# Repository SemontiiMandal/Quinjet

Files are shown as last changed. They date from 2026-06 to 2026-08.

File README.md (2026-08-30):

# Quinjet

A custom mini quadcopter and remote controller. Built entirely from scratch, covering the PCB layout, Zephyr firmware, and flight hardware.



## Hardware Design

Both the flight controller and remote controller were designed from scratch in Altium Designer. You can find all design files, including schematics and PCB layouts here, [Altium-Design-Files](https://github.com/SemontiiMandal/Quinjet/tree/main/Altium-Design-Files).

### Four-Layer Flight Controller

The Flight Controller (FC) uses a four-layer stack-up to isolate high-speed digital signals from the power lines driving the motors.

* **Power Delivery:** Features a dedicated boost converter to maintain stable voltage for the nRF52840 and BMI270 under the high current draw of the motors.
* **Battery Monitoring:** The battery voltage is connected to an ADC channel via a voltage divider, allowing the firmware to track real-time power levels.
* **Motor Control:** Uses low-side MOSFET switching with flyback diodes to protect the MCU from motor voltage spikes.

**Layout and 3D View**

<table>
  <tr>
    <td></td>
    <td></td>
    <td></td>
    <td></td>
  </tr>
</table>

**Schematic**



*Download full schematic [here](https://github.com/SemontiiMandal/Quinjet/blob/main/Altium-Design-Files/Mini-Drone/fc_schematic.pdf).*

### Two-Layer Remote Controller

The Remote Controller (RC) is a two-layer board designed for ergonomic input handling.

* **Input Handling:** Interfaces with two dual-axis analog joysticks, sampled directly by the nRF52840’s built-in 12-bit ADC.
* **Interface:** Includes an I2C-based OLED display for real-time telemetry and a PWM-driven haptic motor for tactile alerts.
* **Power Management:** Uses a low-dropout regulator (LDO) to provide clean 3.3V power to the MCU and peripherals, ensuring consistent ADC and sensor readings.
* **Battery Monitoring:** Here too, the battery voltage is connected to an ADC channel via a voltage divider, allowing the firmware to track real-time power levels.

**Layout and 3D View**

<table>
  <tr>
    <td></td>
    <td></td>
  </tr>
  <tr>
    <td></td>
    <td></td>
  </tr>
</table>

**Schematic**



*Download full schematic [here](https://github.com/SemontiiMandal/Quinjet/blob/main/Altium-Design-Files/Mini-Drone-Remote/rc_schematic.pdf).*

---

## System Components and Interconnections

The Quinjet hardware ecosystem consists of two distinct nodes. Each utilizes the nRF52840's peripheral set to handle real-time sensor fusion, radio communication, and motor control.

### Flight Controller (FC) Hardware

* **BMI270 IMU (SPI):** Connects to the nRF52840 via the SPI bus. It uses a dedicated GPIO interrupt pin to wake the flight controller thread exactly when new sensor data is ready, ensuring 1000Hz synchronization.
* **Coreless Motors (Direct-Drive):** Four MOSFETs are driven directly by the nRF52840’s hardware PWM peripherals, operating at 32kHz for silent operation.
* **ESB Radio:** The 2.4GHz radio handles packets asynchronously via the Nordic ESB stack.

### Remote Controller (RC) Hardware

* **Joysticks (SAADC):** Two dual-axis analog joysticks connect to the nRF52840’s SAADC channels, sampled at 100Hz and normalized for transmission.
* **OLED Display (I2C):** Provides the pilot with real-time telemetry and system status.
* **Vibration Motor:** Driven via PWM to provide physical feedback to the pilot.

### Components Summary

| Peripheral | Board | Interface | Purpose |
| --- | --- | --- | --- |
| **BMI270** | FC | SPI | 6-Axis Motion Tracking |
| **Motors (x4)** | FC | PWM | Coreless DC Motor Control |
| **Joysticks** | RC | SAADC | Pilot Input |
| **OLED** | RC | I2C | Telemetry Display |
| **Radio Link** | Both | ESB (2.4GHz) | Low-latency control |

---

## Firmware Architecture

### Flight Controller Board

The Flight Controller (FC) is a high-performance, real-time system engineered to maintain a strict, 1000Hz control loop, ensuring the drone responds to flight dynamics with millisecond precision.

* **Physics-First Timing:** The firmware is driven by a hardware interrupt from the BMI270 IMU. This ensures the flight loop runs at a deterministic 1000Hz, perfectly synchronized to the physical reality of the drone's orientation.
* **Lock-Free Concurrency:** The system uses `k_spinlock` for memory protection, allowing the radio radio to asynchronously dump pilot commands into shared memory without ever blocking the critical PID loop or halting the Zephyr scheduler.
* **Safety & Control:** The system features a custom PID implementation with Anti-Windup logic and a Motor Mixer that acts as a hardware kill-switch, ensuring motors only spin when explicitly armed and commanded.

**For a deep dive into flight dynamics, spinlock logic, and PID tuning, see the [Flight Controller Architecture Documentation](https://github.com/SemontiiMandal/Quinjet/blob/main/firmware/flight_controller/Architecture.md).**

### CMSIS-DSP Library & Filters to Optimize Flight Dynamics

#### Dynamic Notch Filtering & Sliding Window FFT
Motor noise frequencies shift based on throttle. The firmware uses a sliding-window FFT to track this. It maintains an overlapping 64-sample buffer with a hop size of 8. A Hann window is applied, and a fast Fourier transform (`arm_rfft_fast_f32`) executes every 8ms to find the peak noise frequency. A biquad notch filter then removes this frequency before the data reaches the PID controller.

#### Derivative Kick & Anti-Windup
The PID calculates the derivative on the physical measurement instead of the error to prevent derivative kick. It also uses back-calculation anti-windup: if commanded motor output exceeds 100%, the excess power is calculated and drained from the integral term.

#### Dynamic Mixer Scaling & Radio Failsafe
The mixer allows 100% throttle inputs. If a motor exceeds 100% duty cycle, all motors are scaled down equally to preserve differential thrust for stabilization. A radio failsafe checks `k_uptime_get()` and sets PWM to 0 if the RC signal is lost for 500ms.

#### Hardware FPU Optimization
The DSP data path uses 32-bit `float` types exclusively. This ensures sensor fusion and biquad filters execute on the nRF52840's hardware Floating-Point Unit (FPU) instead of using software emulation.

---
### Remote Controller Board

The Quinjet system utilizes a custom, low-latency firmware stack built on **Zephyr RTOS**. The remote controller and flight controller communicate via a proprietary Enhanced ShockBurst (ESB) radio link, sharing a strictly packed data structure for real-time control input.

* **Producer-Consumer Design:** The system uses a lock-free approach where the ADC thread produces joystick state, and the radio thread consumes it via semaphore-driven wakeups.
* **Hardware Safety:** The Remote Controller features a custom state machine that enforces a Zero-Throttle Gate, preventing the drone from arming unless the throttle stick is physically at the zero position.
* **Resource Safety:** Shared memory between threads is protected by mutexes, ensuring thread-safe operations during high-frequency telemetry updates.

**For a deep dive into the firmware design, concurrency models, and interrupt-driven logic, see the [Remote Controller Architecture Documentation](https://github.com/SemontiiMandal/Quinjet/blob/Separate-controller/firmware/remote_controller/Architecture.md).**

---

## Pics of Assembly in progress
WhatsApp Image 2026-06-20 at 6 49 02 PM



## Testing IMU SPI init and value reading (stationary board)


## Testing Remote Controller (RC) Transmission (no RX connected yet)


## Testing Flight Controller


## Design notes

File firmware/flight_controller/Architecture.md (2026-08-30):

# Quinjet Flight Controller Architecture

The Quinjet Flight Controller (FC) runs on an nRF52840 using Zephyr RTOS. The flight control loop executes at 1kHz, driven directly by a hardware interrupt from the BMI270 IMU.

## 1. Core Workflow

The system handles asynchronous radio commands while maintaining a synchronous 1kHz flight loop.

* **IMU Interrupt (1kHz Base):** The BMI270 triggers a hardware interrupt every 1ms when new data is ready. This ISR uses a semaphore (`imu_data_ready_sem`) to wake the flight control thread.
* **Radio Reception:** The ESB radio receives pilot commands asynchronously via the `esb_callback` ISR.
* **Spinlock Protection:** Radio data is protected using `k_spinlock`. This briefly disables local CPU interrupts to safely copy data into shared memory without halting the Zephyr scheduler or delaying the 1kHz loop.
* **Radio Failsafe:** The thread checks Zephyr's `k_uptime_get()`. If no valid radio packet is received for 500ms, the system triggers a hardware failsafe, dropping motor duty cycles to 0.
* **Flight Control Thread:** Statically allocated (`K_THREAD_DEFINE`) as a cooperative thread (Priority -1). It wakes, executes DSP and PID calculations uninterrupted, and immediately yields back to the scheduler.

## 2. Flight Dynamics

* **Back-Calculation Anti-Windup:** The PID loops track hardware saturation. If outputs demand more than 100% motor power, the system calculates the excess "phantom power" and subtracts it from the integral memory to prevent overshoot.
* **Measurement Derivative:** The D-term is calculated on the rate of change of the physical measurement rather than the error, preventing derivative kick during rapid joystick movements.
* **Dynamic Mixer Scaling & AirMode:** The motor mixer evaluates all four commanded outputs. If a motor exceeds 100% duty cycle, the mixer mathematically scales all four motors down equally to preserve differential thrust without an artificial throttle cap. It also scales motors up (AirMode) if they drop below minimum idle speed to maintain stabilization during free-fall.

## 3. Digital Signal Processing (DSP) Pipeline

The DSP pipeline cleans the raw sensor data before feeding it to the PID controller.

* **Data Ingestion (1kHz):** Driven by the 1ms IMU interrupt, raw accelerometer and gyroscope data is read and cast directly to 32-bit `float` variables. This locks the pipeline inside the nRF52840's hardware Floating-Point Unit (FPU), bypassing software math emulation.
* **Sliding Window FFT:** The system uses `memmove` to shift an overlapping 64-sample buffer every 1ms. Every 8ms (an 8-sample hop size), a pre-calculated Hann window is applied, and a CMSIS-DSP fast Fourier transform (`arm_rfft_fast_f32`) executes to identify the dominant motor resonance in the 100Hz–400Hz band.
* **Dynamic Notch Filter:** A biquad notch filter updates its center frequency based on the FFT output to mathematically remove the specific motor vibration peak from the gyroscope data.
* **Sensor Fusion:** A complementary filter (`Angle = 0.98 * (Angle + Gyro * dt) + 0.02 * Accel_Angle`) calculates orientation. It uses the gyroscope for short-term tracking and the accelerometer as a long-term reference to correct drift.
* **D-Term Smoothing:** The D-term passes through an independent 30Hz CMSIS biquad low-pass filter to prevent high-frequency noise from reaching the motors.

## 4. Architectural Design Concepts

| Concept | Implementation Strategy |
| --- | --- |
| **Interrupt-Safe Memory** | Using `k_spinlock` instead of mutexes ensures the radio can dump data into shared memory without halting the Zephyr scheduler or delaying the 1000Hz flight loop. |
| **No Stale Data** | We do not queue or buffer incoming radio packets. The PID loop only reads the single newest command. Queuing would force the drone to execute outdated maneuvers. |
| **High-Frequency PWM** | The DeviceTree overrides standard PWM defaults to drive the coreless motors at **32 kHz**. This is above human hearing and prevents electrical switching noise from interfering with the IMU. |

## 5. Logical Flow Summary

The system runs a continuous, low-latency loop, triggered by the IMU data-ready interrupts:

1. **Input:** The Radio ISR updates the shared memory buffer with pilot commands in the background.
2. **Trigger:** The BMI270 finishes a reading and fires an interrupt, waking the main thread.
3. **Failsafe Check:** The thread verifies the radio connection timestamp via OS uptime.
4. **Processing:** The thread fetches the IMU data, runs the DSP pipeline, executes Sensor Fusion, and calculates Pitch, Roll, and Yaw PID corrections.
5. **Mixing:** The PID outputs are mapped to the physical Quad-X motor layout using dynamic overflow scaling.
6. **Output:** The final duty cycles (0–10000) are sent to the hardware PWM registers to update the motor speeds.

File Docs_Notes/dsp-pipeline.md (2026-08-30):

# Quinjet Digital Signal Processing (DSP) Pipeline

## 1. Data Ingestion & Formatting

The BMI270 IMU triggers a hardware interrupt every 1 millisecond. Raw 16-bit integer readings are fetched via SPI and immediately converted into standard floating-point metrics (m/s² for acceleration, rad/s for angular velocity). This strictly enforces FPU hardware execution for all subsequent stages.

## 2. Resonance Detection (Sliding Window FFT)

Motors and propellers generate high-frequency vibrations that travel through the frame into the gyroscope. To find this noise peak without delaying the flight loop, we use an overlapping sliding window FFT.

* **The Buffer Shift:** Every 1ms, a 64-sample buffer shifts left by one, dropping the oldest reading and appending the newest.
* **The Hop Size:** Every 8 milliseconds, the FFT executes on the 64-sample snapshot.
* **The Hann Window:** Before the FFT runs, the raw data is multiplied by a Hann window to taper the edges to zero. This prevents the FFT from seeing the chunk's boundaries as sudden, high-frequency "cliffs" (spectral leakage). The window is pre-calculated on boot:

$$w[n] = 0.5 \left( 1 - \cos\left(\frac{2\pi n}{N-1}\right) \right)$$

* **Magnitude Calculation:** The CMSIS-DSP `arm_rfft_fast_f32` function returns interleaved real and imaginary numbers. The true amplitude of each frequency bin $k$ is calculated as:

$$M[k] = \sqrt{\text{Re}(X[k])^2 + \text{Im}(X[k])^2}$$

The algorithm scans the 100Hz–400Hz range to pinpoint the exact frequency $f_c$ with the highest magnitude.

## 3. Dynamic Notch Filtering

Once the FFT identifies the peak motor resonance, passing it through a Biquad Notch Filter eliminates specific frequency from the gyroscope data.

As the pilot adjusts the throttle and the motor RPM shifts, the FFT detects the new vibration frequency and dynamically recalculates the biquad filter coefficients ($a_n$, $b_n$). The filter operates using the standard discrete-time transfer function:

$$H(z) = \frac{b_0 + b_1 z^{-1} + b_2 z^{-2}}{a_0 + a_1 z^{-1} + a_2 z^{-2}}$$

This basically neutralizes motor noise while passing the lower-frequency physical drone rotations through.

## 4. Sensor Fusion (Complementary Filter)

Now the system determines the drone's true orientation by fusing the gyroscope and accelerometer.

* **Accelerometer (Absolute but Noisy):** Trigonometry determines the angle relative to gravity.

$$\phi_{acc} = \arctan\left(\frac{a_y}{\sqrt{a_x^2 + a_z^2}}\right)$$

* **Gyroscope (Fast but Drifts):** The angular velocity is multiplied by the loop time ($dt = 0.001$) to find the rotation amount.
* **The Fusion:** A complementary filter merges them. It trusts the gyroscope for 98% of the split-second maneuver and mixes in 2% of the accelerometer to permanently anchor the horizon and prevent gyro drift:

$$\theta = \alpha (\theta + \omega dt) + (1 - \alpha) \theta_{acc}$$

*(where $\alpha = 0.98$)*

## 5. PID Control & D-Term Smoothing

Next, the PID controller calculates the motor adjustments needed to match the pilot's requested angle.

* **Measurement Derivative:** Derivative kick is a sudden, massive spike in the control output of a PID controller caused by an abrupt change in the setpoint. To prevent derivative kick if the pilot rapidly changes the joystick to a new setpoint, the derivative (braking) force is calculated purely on the rate of change of the drone's physical movement, ignoring the mathematical error:

$$D_{raw} = -\left(\frac{\text{Measured}_t - \text{Measured}_{t-1}}{dt}\right)$$

* **D-Term Low-Pass Filter:** Because taking a derivative mathematically amplifies any microscopic jitter left over from the notch filter, the raw D-term is passed through a dedicated 30Hz Biquad Low-Pass filter before it can multiply with the $K_d$ gain.
* **Back-Calculation Anti-Windup:** If the final PID output demands a duty cycle greater than 100%, the difference ($E_{excess}$) is instantly subtracted from the integral sum ($I_{sum}$) scaled by a back-tracking gain ($K_b$). This ensures the integral memory never winds up beyond the physical limits of the motors:

$$I_{sum} = I_{sum} - (E_{excess} \cdot K_b \cdot dt)$$

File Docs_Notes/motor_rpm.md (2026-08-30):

# 8520 Coreless Motor PWM Control Profile

This document details the relationship between the applied **32 kHz PWM signal** and the resulting **RPM** for the Powerday 8520 coreless brushed motor powered by a **4.2V lipo battery source**.

---

## 1. Motor & Signal Parameters

### Baseline Specifications
* **Max Speed (No-Load):** 53,000 RPM @ 5.0V
* **Target Source Voltage ($V_{\text{source}}$):** 4.2V (1S LiPo max)
* **PWM Carrier Frequency ($f$):** 32,000 Hz (32 kHz)

### Derived Constants
* **Motor Velocity Constant ($K_v$):**
  $$K_v = \frac{53,000 \text{ RPM}}{5.0\text{V}} = 10,600 \text{ RPM/V}$$
* **PWM Period ($T$):** The exact timeframe for one complete ON/OFF cycle.
  $$T = \frac{1}{f} = \frac{1}{32,000 \text{ Hz}} = 31.25\ \mu\text{s}$$

---

## 2. Core Mathematical Formulas

The system relies on three interconnected equations to translate software values to mechanical motion:

1. **Pulse ON Time ($T_{\text{on}}$):**
   $$T_{\text{on}} = T \times \text{Duty Cycle } (D)$$
2. **Average Output Voltage ($V_{\text{avg}}$):**
   $$V_{\text{avg}} = V_{\text{source}} \times \text{Duty Cycle } (D)$$
3. **Theoretical Motor Speed ($\text{RPM}_{\text{ideal}}$):**
   $$\text{RPM}_{\text{ideal}} = V_{\text{avg}} \times K_v$$

---

## 3. Detailed Duty Cycle Calculations (4.2V Source)

Below are three operational reference scenarios calculated across the voltage profile.

### Scenario A: 100% Duty Cycle (Full Throttle)
* **Duty Cycle ($D$):** $1.0$
* **ON Time ($T_{\text{on}}$):** $31.25\ \mu\text{s} \times 1.0 = 31.25\ \mu\text{s}$ (Continuous high state)
* **Average Voltage ($V_{\text{avg}}$):** $4.2\text{V} \times 1.0 = 4.2\text{V}$
* **Calculation:**
  $$\text{RPM} = 4.2\text{V} \times 10,600 \text{ RPM/V} = \mathbf{44,520 \text{ RPM}}$$

### Scenario B: 75% Duty Cycle (Cruising Speed)
* **Duty Cycle ($D$):** $0.75$
* **ON Time ($T_{\text{on}}$):** $31.25\ \mu\text{s} \times 0.75 = 23.4375\ \mu\text{s}$
* **Average Voltage ($V_{\text{avg}}$):** $4.2\text{V} \times 0.75 = 3.15\text{V}$
* **Calculation:**
  $$\text{RPM} = 3.15\text{V} \times 10,600 \text{ RPM/V} = \mathbf{33,390 \text{ RPM}}$$

### Scenario C: 25% Duty Cycle (Low Speed/Idle)
* **Duty Cycle ($D$):** $0.25$
* **ON Time ($T_{\text{on}}$):** $31.25\ \mu\text{s} \times 0.25 = 7.8125\ \mu\text{s}$
* **Average Voltage ($V_{\text{avg}}$):** $4.2\text{V} \times 0.25 = 1.05\text{V}$
* **Calculation:**
  $$\text{RPM} = 1.05\text{V} \times 10,600 \text{ RPM/V} = \mathbf{11,130 \text{ RPM}}$$

---

## 4. Summary Duty Cycle to RPM Lookup Table

The following theoretical lookup table assumes an 8-bit resolution microcontroller layout (0 - 255 steps) mapping to the 4.2V ceiling.

| 8-Bit Step | Duty Cycle (%) | Average Voltage ($V_{\text{avg}}$) | Theoretical No-Load RPM |
| :--- | :--- | :--- | :--- |
| **255** | 100% | 4.20V | 44,520 RPM |
| **204** | 80% | 3.36V | 35,616 RPM |
| **153** | 60% | 2.52V | 26,712 RPM |
| **102** | 40% | 1.68V | 17,808 RPM |
| **51** | 20% | 0.84V | 8,904 RPM |
| **25** | ~10% | 0.42V | *Friction Threshold Boundary* |

---

## 5. Physical Implementation Constraints

1. **Aerodynamic Loading (75mm Propeller):** 
   The calculation yields *no-load* RPM metrics. Attaching the 75mm propeller introduces aerodynamic drag torque. Because propeller power demands scale cubically with velocity ($P \propto \text{RPM}^3$), the linear voltage-to-RPM relationship will **flatten out aggressively at high duty cycles**. Actual operational RPM will sit lower than theoretical models.
2. **High Carrier Frequency Advantage:** 
   Utilizing a **32 kHz** carrier provides an ultrashort period ($31.25\ \mu\text{s}$). Coreless motors have ultra low core inductance, so standard low-frequency PWM signals cause current ripples, causing heating up and motor ripple. A 32 kHz frequency not only ensures clean and steady DC equivalence, but also dampens audible switching out of human hearing range!

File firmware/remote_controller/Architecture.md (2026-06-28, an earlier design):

# Quinjet RC Controller Architecture

The Quinjet Remote Controller firmware is a real-time system built on the **nRF52840** and **Zephyr RTOS**. It is engineered to maintain a strict, low-latency hot path from the user’s fingertips to the radio transmitter, ensuring the drone responds instantly to pilot commands.

## 1. Core Workflow

The system operates as a producer-consumer engine where data flows from hardware sensors to the radio link through protected memory.

* **Joystick Sampling (Producer):** The `adc_thread` runs a deterministic 100Hz loop (every 10ms). It queries four ADC channels, converts the raw 12-bit hardware values into normalized floating-point coordinates (`-1.0` to `1.0`), and applies dead-zone and jitter compensation logic.
* **Resource Protection:** To prevent "data tearing" (where the radio sends a partially updated packet), the system **protects shared resources with a mutex** (`joystick_data`). The ADC thread locks this mutex before updating the shared `data_packet`, and the radio thread locks it before reading the payload.
* **Thread Synchronization:** Efficiency is achieved by letting the radio thread sleep when no new data is present. The ADC thread **wakes the radio thread by giving a semaphore** (`wake_esb`) immediately after it has finished refreshing the shared memory, effectively triggering the transmission only when absolutely necessary.
* **Air Link (Consumer):** The `esb_tx_thread` remains blocked, consuming zero CPU cycles until the semaphore wakes it. Once active, it creates a local snapshot of the control state, releases the mutex, and blasts the packet over the 2.4GHz Enhanced ShockBurst (ESB) link.

## 2. Safety and State Management

Flying hardware requires strict safety gates. We move away from polling in favor of hardware-level event handling.

* **Interrupt-Driven Logic:** The `rc_state_machine` uses physical GPIO interrupts on the joystick buttons. When a button is pressed, the ISR fires instantly to flip a `volatile bool` flag. This avoids the latency and CPU waste of checking pin states in a loop.
* **The Zero-Throttle Gate:** We implement a software-defined safety gate. The transition from `IDLE` to `ARMED` is only permitted if the `throttle` coordinate is below `0.05f` (near zero). This prevents the drone from jumping into the air if the stick is accidentally left pushed forward during the arming sequence.

## 3. Architectural Design Concepts

| Concept | Implementation Strategy |
| --- | --- |
| **Data Packing** | We use `__attribute__((packed))` on the shared `data_packet` struct. This forces the compiler to ignore padding bytes, ensuring the RC transmitter and FC receiver interpret the memory layout identically over the air. |
| **Modularity** | The system is split into `rc/`, `fc/`, and `shared/` directories. Common structs (like the 20-byte `data_packet`) reside in `shared/`, ensuring that if you update your packet format, both boards stay in sync. |
| **Jitter Mitigation** | The `decode_joystick` module performs software-based noise filtering on ADC samples. By mapping raw values to a consistent coordinate space, the flight controller remains agnostic to the specific potentiometer hardware used. |
| **Deterministic Timing** | By using `k_msleep(10)` for our control loop, we provide the Flight Controller with a perfectly steady stream of data, which is essential for stable PID loop performance. |

## 4. Logical Flow Summary

The system behaves as a synchronous link between the pilot and the flight hardware:

1. **Input:** Pilot moves the joysticks or toggles the arm button.
2. **Processing:** The ADC thread performs normalization and enforces the "Zero-Throttle" safety gate.
3. **Synchronization:** The shared memory is updated, and the radio thread is woken via semaphore.
4. **Transmission:** The radio thread copies the struct, handles ESB auto-ACKs, and pushes the data to the air interface.

This architecture ensures that the hot path is never blocked by slow radio hardware or erratic button presses, providing the literal locked-in feel required for reliable flight control!

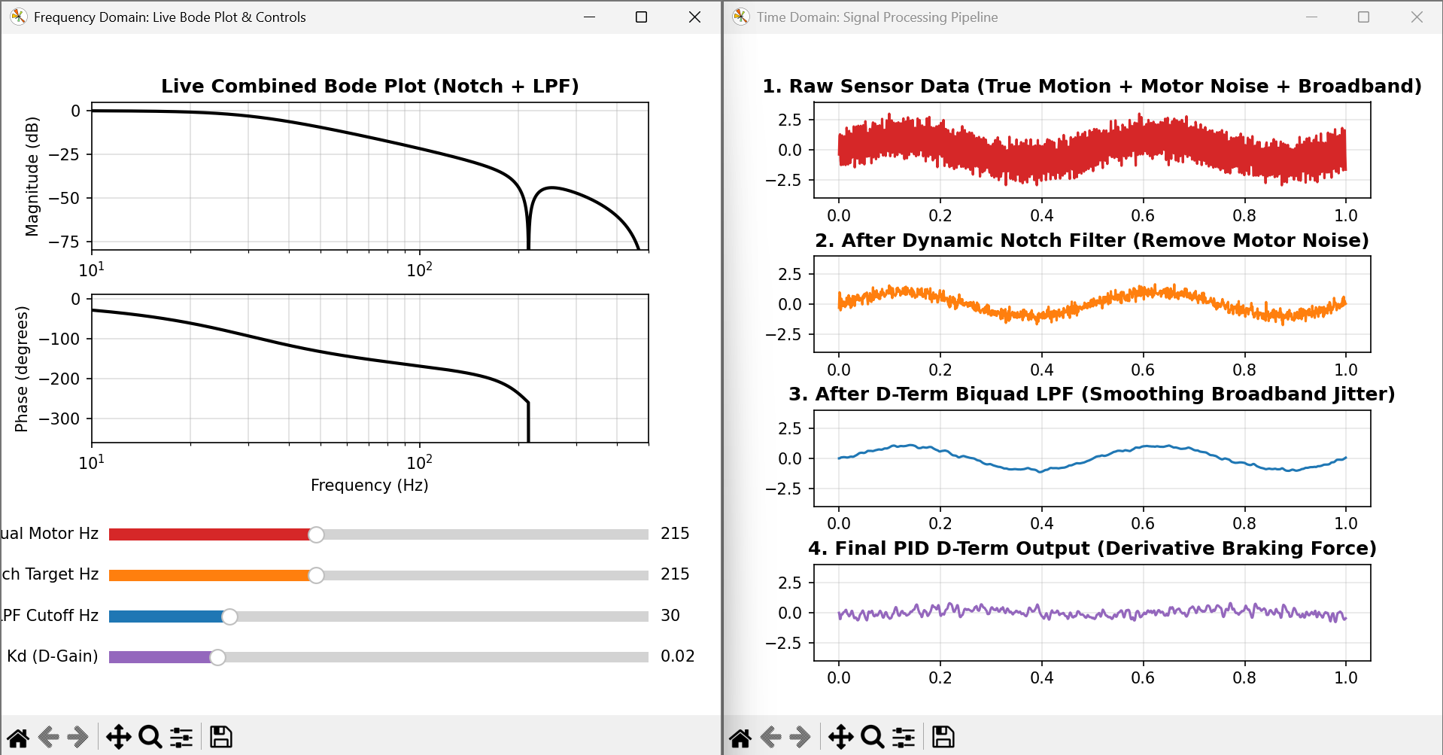
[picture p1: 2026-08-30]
software/simulations_dsp.png

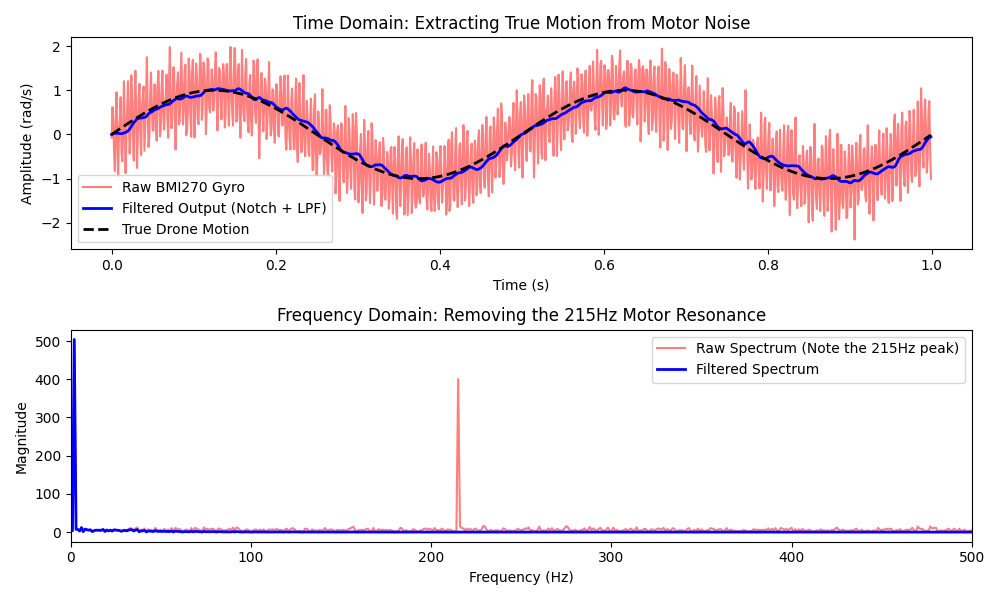
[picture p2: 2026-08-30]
software/dsp_pipeline_stage.png

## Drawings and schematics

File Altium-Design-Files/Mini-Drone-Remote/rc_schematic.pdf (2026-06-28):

REVISION | DESCRIPTION | DATE | APPROVED | REV. SHT. <SCH DWG NO> 1 DWG. NO.

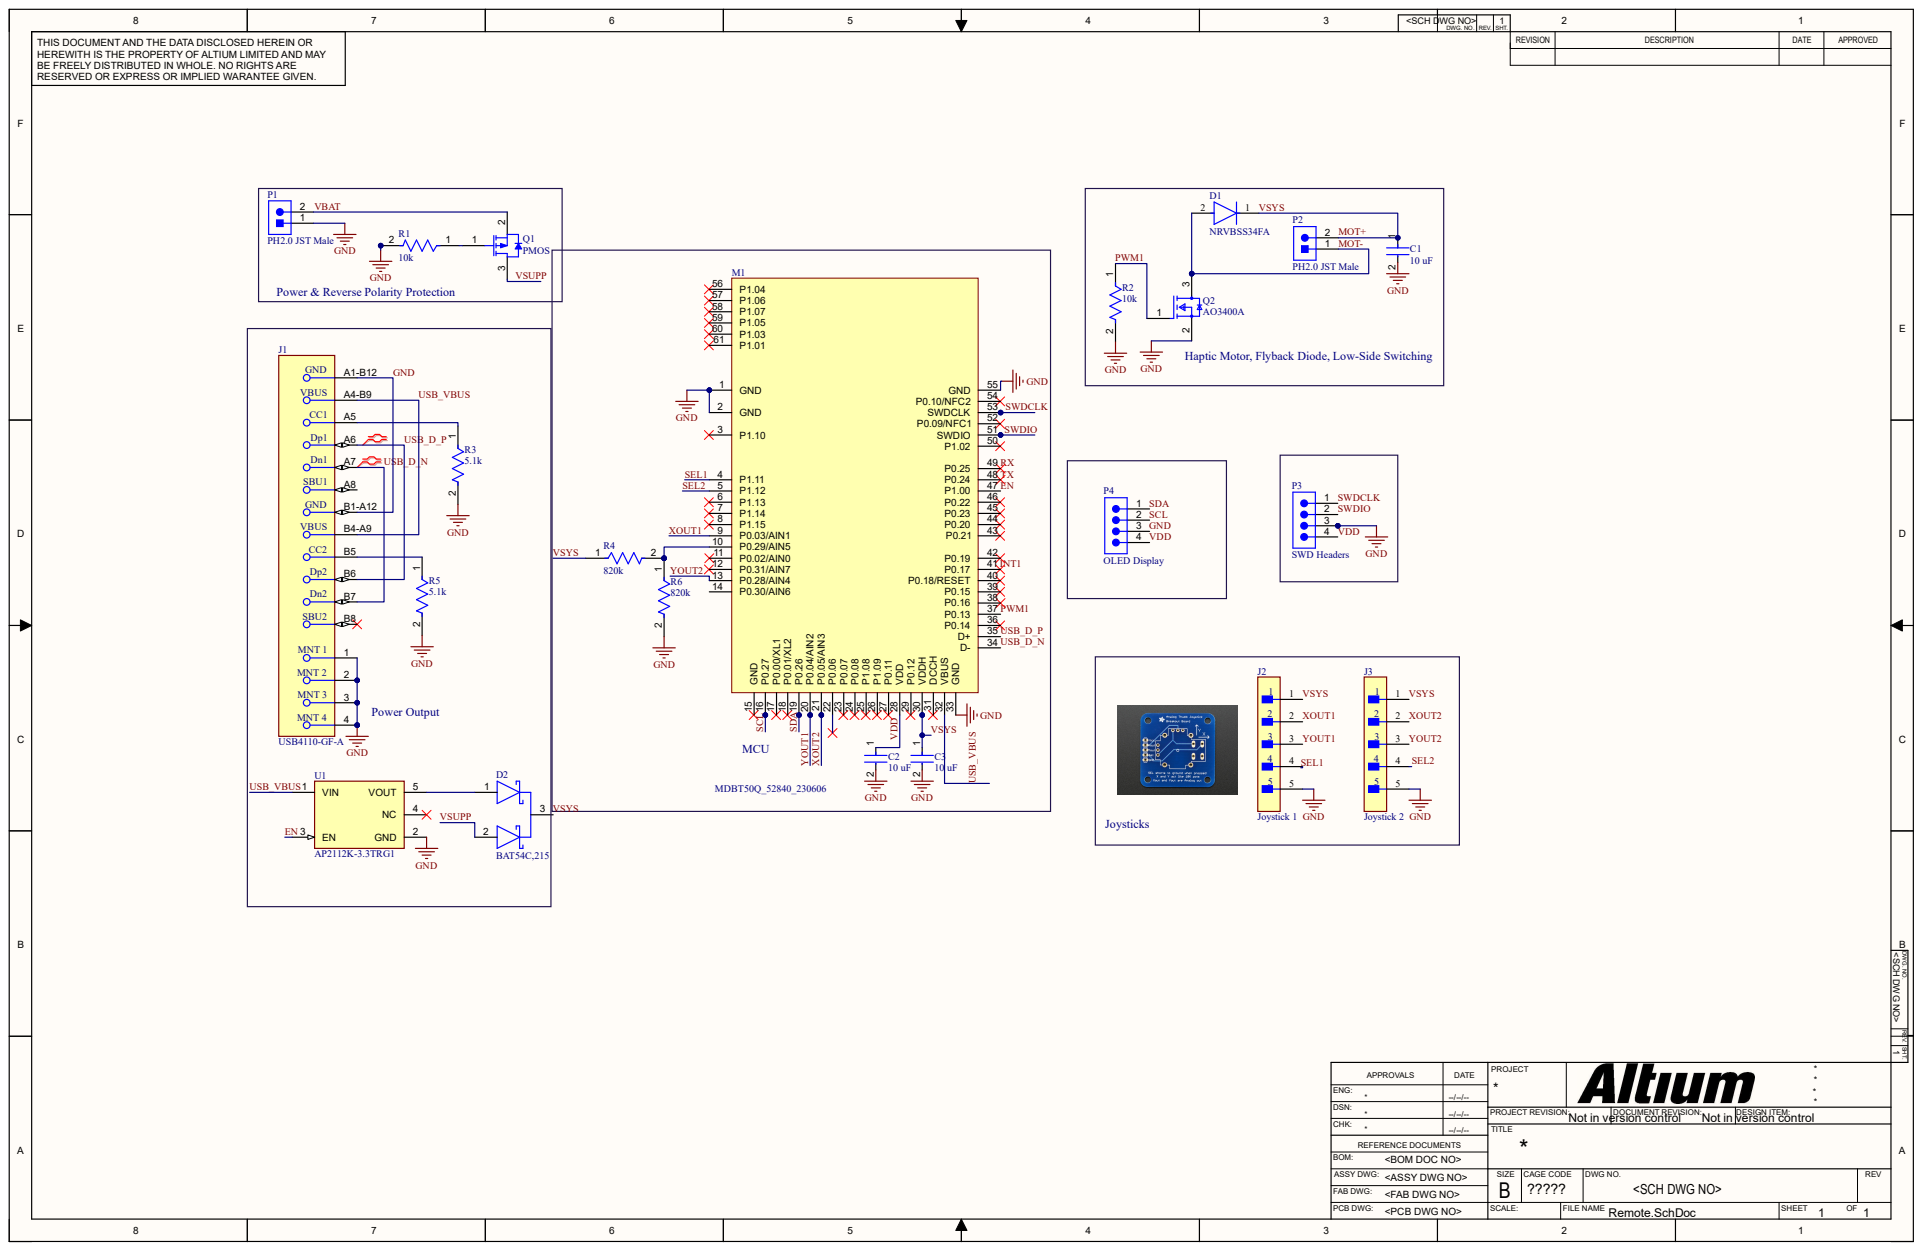
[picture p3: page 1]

8 | 7 | 6 | 5 | 4 | 3 | <SCH DWG NO> | DWG. NO. | REV. | 1 SHT. | 2 | 1

THIS DOCUMENT AND THE DATA DISCLOSED HEREIN OR HEREWITH IS THE PROPERTY OF ALTIUM LIMITED AND MAY BE FREELY DISTRIBUTED IN WHOLE. NO RIGHTS ARE RESERVED OR EXPRESS OR IMPLIED WARANTEE GIVEN. | D1

Power & Reverse Polarity Protection

Haptic Motor, Flyback Diode, Low-Side Switching

APPROVALS | DATE | PROJECT * | * *

ENG: * | --/--/--
CHK: * | --/--/-- | TITLE *

DSN: * | --/--/-- | PROJECT REVISION: | DOCUMENT REVISION: Not in version control | DESIGN ITEM: Not in version control

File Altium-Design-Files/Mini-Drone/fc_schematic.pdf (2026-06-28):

REVISION | DESCRIPTION | DATE | APPROVED | REV. SHT. <SCH DWG NO> 1 DWG. NO.

10k 1 2

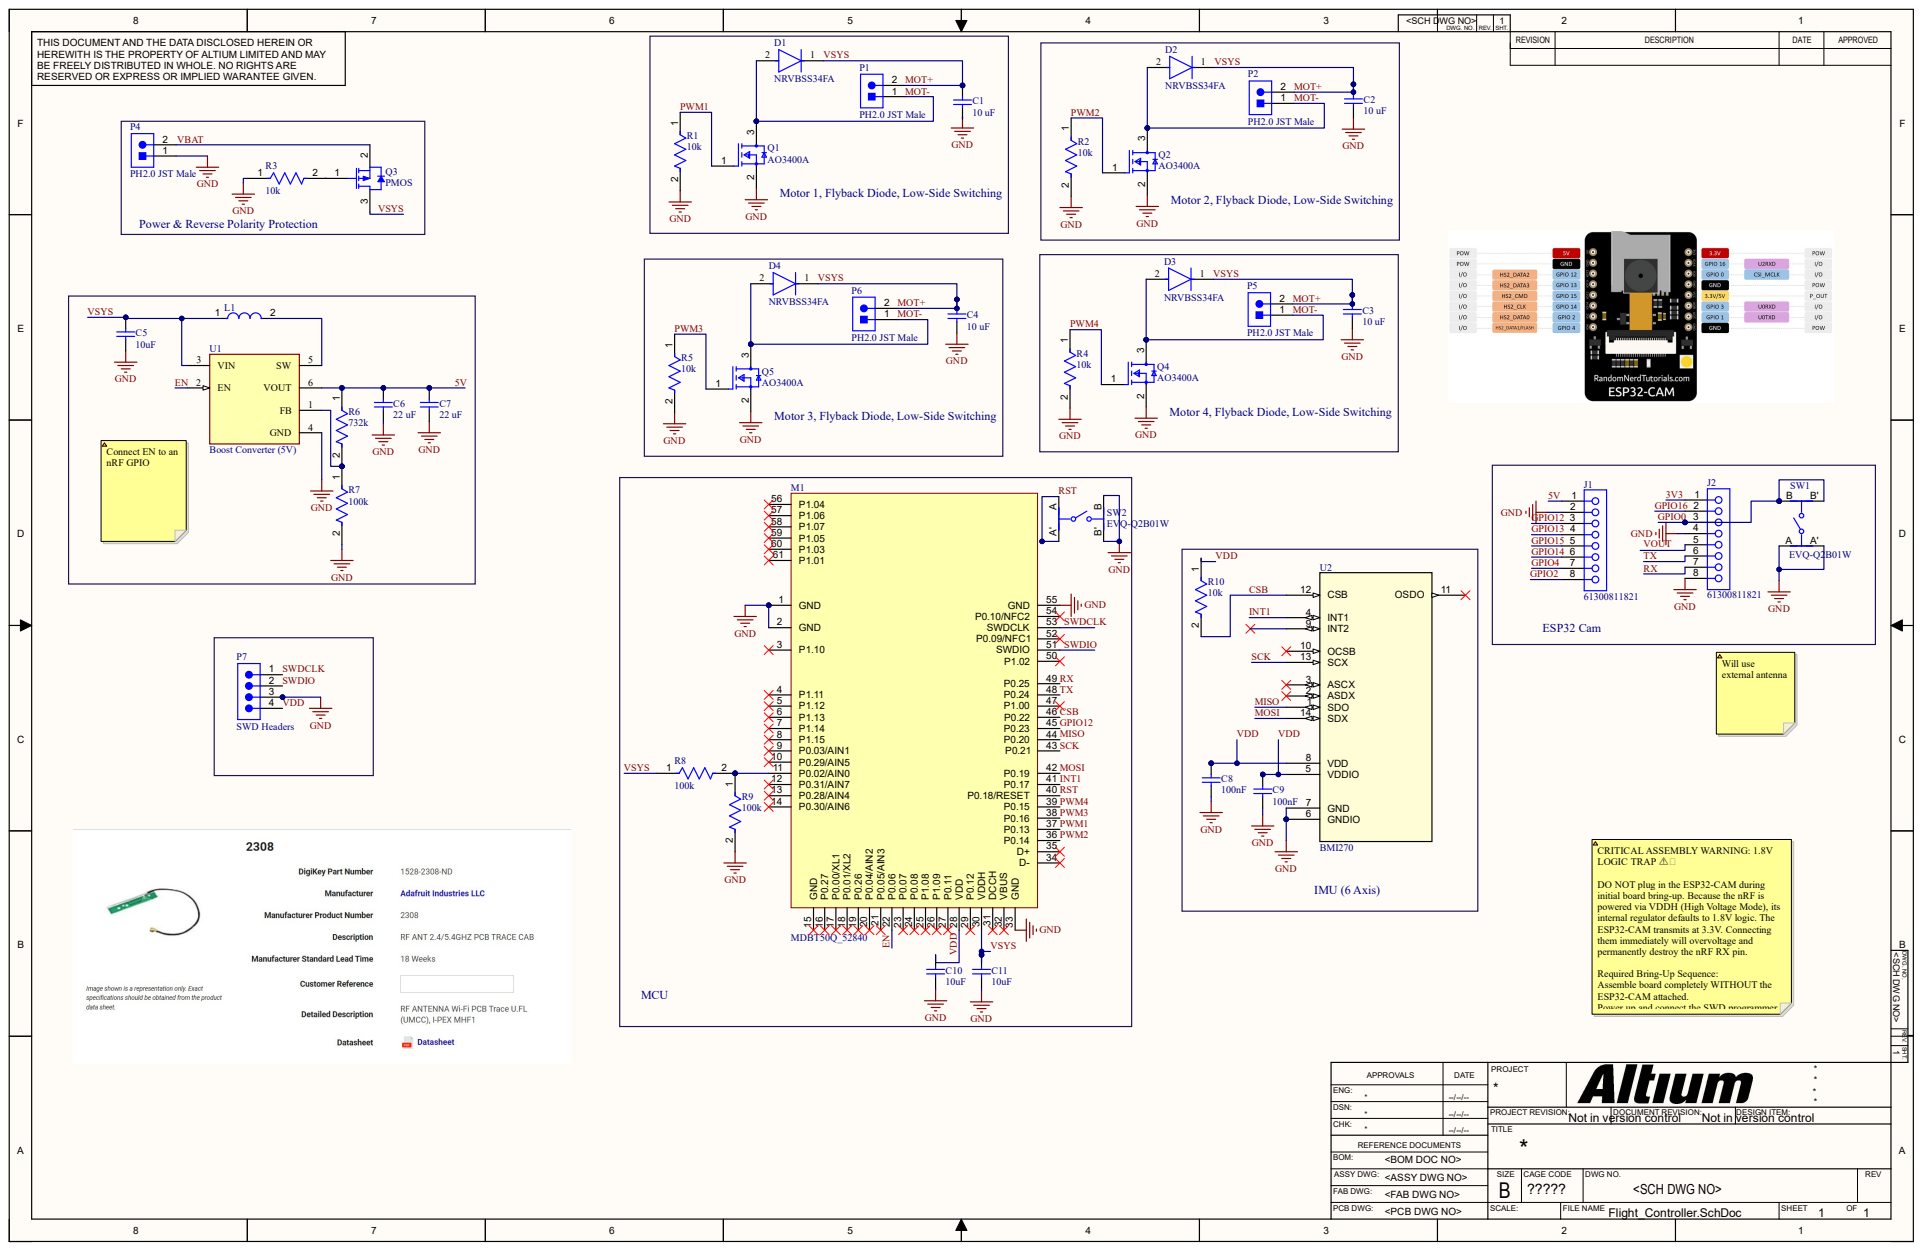
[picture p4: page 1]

8 | 7 | 6 | 5 | 4 | 3 | <SCH DWG NO> | DWG. NO. | REV. | 1 SHT. | 2 | 1

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

Motor 1, Flyback Diode, Low-Side Switching

Motor 2, Flyback Diode, Low-Side Switching

Power & Reverse Polarity Protection

Motor 3, Flyback Diode, Low-Side Switching

Motor 4, Flyback Diode, Low-Side Switching

Connect EN to an
nRF GPIO

DO NOT plug in the ESP32-CAM during
initial board bring-up. Because the nRF is
powered via VDDH (High Voltage Mode), its
internal regulator defaults to 1.8V logic. The
ESP32-CAM transmits at 3.3V. Connecting
them immediately will overvoltage and
permanently destroy the nRF RX pin.

Required Bring-Up Sequence:
Assemble board completely WITHOUT the
ESP32-CAM attached.
Power up and connect the SWD programmer.

APPROVALS | DATE | PROJECT * | * *

ENG: * | --/--/--
CHK: * | --/--/-- | TITLE *

DSN: * | --/--/-- | PROJECT REVISION: | DOCUMENT REVISION: Not in version control | DESIGN ITEM: Not in version control

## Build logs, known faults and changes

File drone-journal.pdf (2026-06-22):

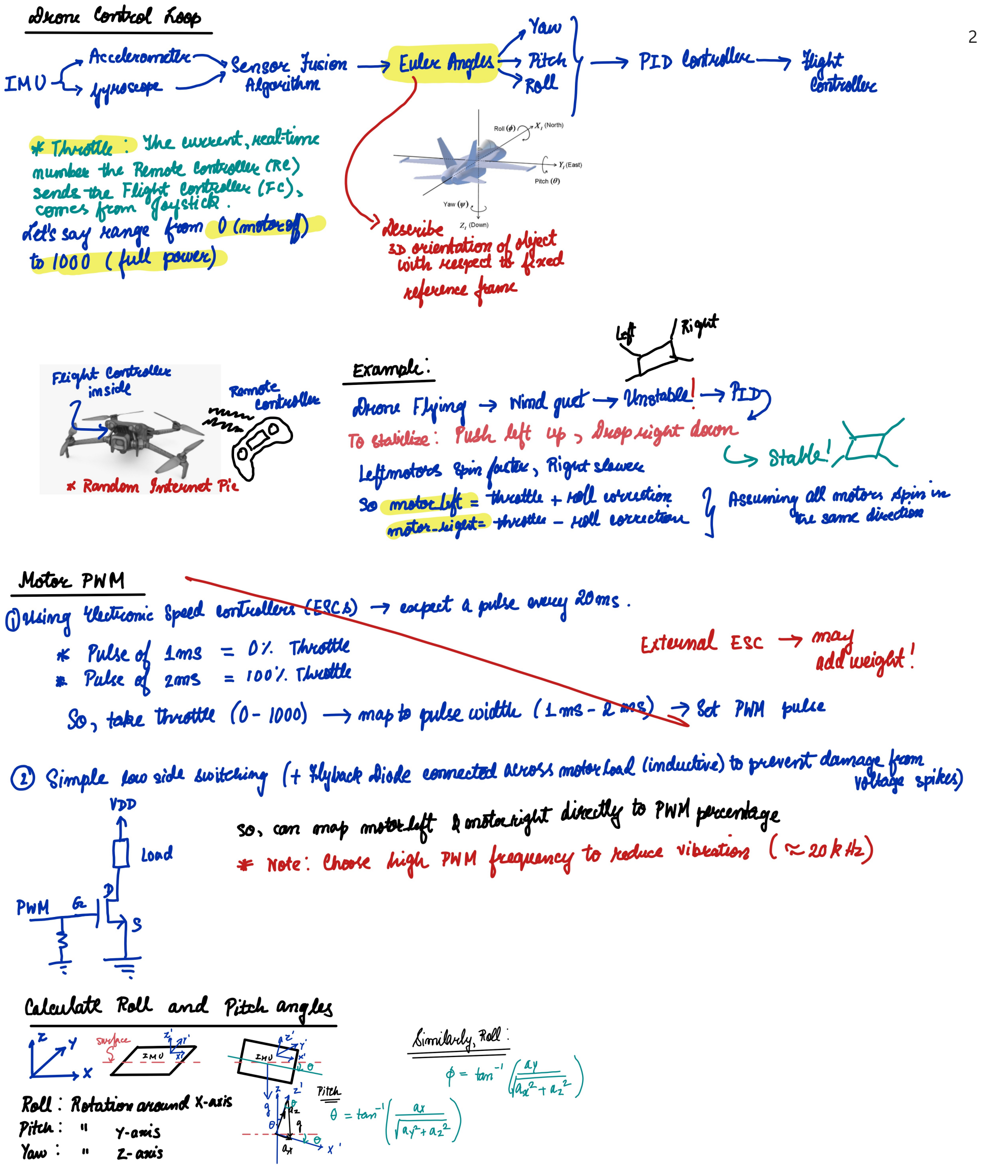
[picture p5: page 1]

2

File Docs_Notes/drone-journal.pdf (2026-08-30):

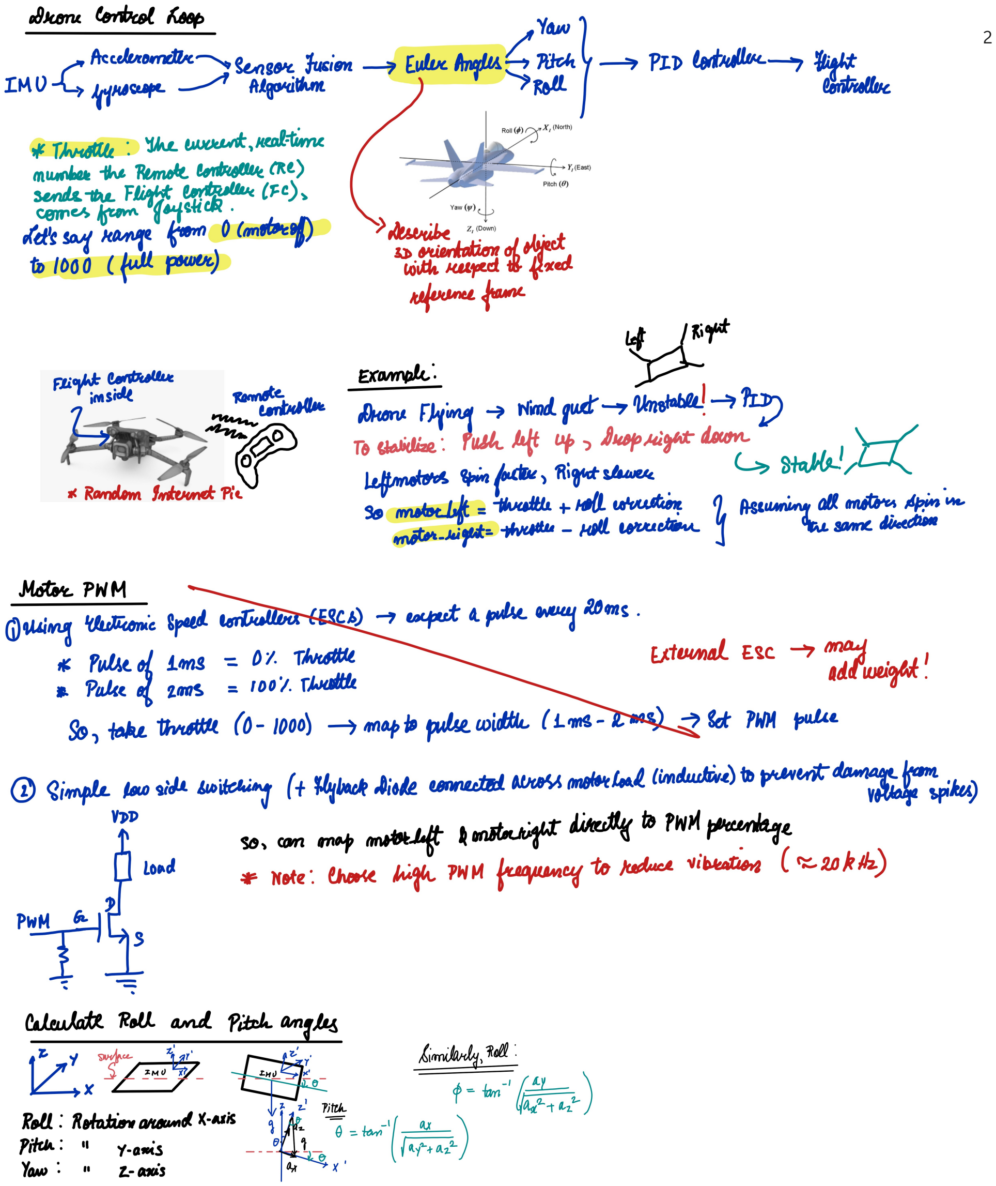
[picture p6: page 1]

2

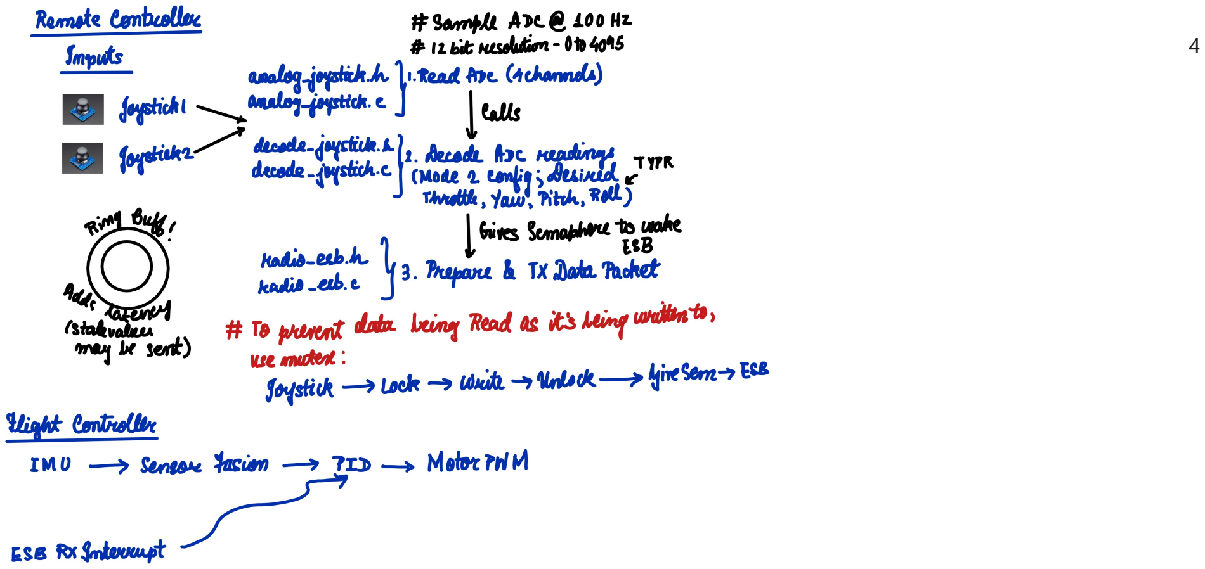
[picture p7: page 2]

4

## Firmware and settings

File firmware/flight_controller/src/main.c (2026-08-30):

#include <zephyr/kernel.h>
#include <zephyr/sys/printk.h>

#include "radio_esb.h"
#include "drivers/motor_pwm.h"

// Expose the BMI init here
extern int bmi270_init(void);

int main(void) {
    printk("\n Booting Quinjet FC \n");

    if (app_pwm_init() != 0) {
        printk("Failed to init PWM.\n");
    }

    if (bmi270_init() != 0) {
        printk("Failed to init IMU.\n");
    }

    if (radio_esb_init(false) != 0) { // false = PRX (Receiver)
        printk("Failed to boot radio.\n");
    }

    printk("System Ready. Flight Controller locked to IMU interrupts.\n");
    
    k_sleep(K_FOREVER);
    return 0;
}

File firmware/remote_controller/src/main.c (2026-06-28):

#include <zephyr/kernel.h>
#include <zephyr/sys/printk.h>

#include "radio_esb.h"
#include "rc_state_machine.h"
#include "drivers/analog_joystick.h"

int main(void) {
    printk("\n--- Booting Quinjet RC ---\n");

    if (rc_state_init() != 0) {
        printk("Failed to init buttons.\n");
    }

    if (joystick_init() != 0) {
        printk("Failed to init ADC.\n");
    }

    if (radio_esb_init(true) != 0) { // true = PTX
        printk("Failed to boot radio.\n");
    }

    printk("System Ready. Threads running in background.\n");
    
    // Main thread can just sleep forever now, the RTOS threads are doing the work
    k_sleep(K_FOREVER);
    return 0;
}

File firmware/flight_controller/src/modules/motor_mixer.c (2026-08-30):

#include <stdint.h>
#include "drivers/motor_pwm.h"

// Direct-Drive PWM Boundaries (0% to 100% Duty Cycle)
#define MAX_DUTY_CYCLE 10000.0f  // 100% power
#define MIN_ARMED_DUTY 500.0f    // 5% power to keep props spinning when armed
#define MOTOR_OFF      0         // 0% power

motor_outputs_t mix_motors(float throttle_rc, float pitch_pid, float roll_pid, float yaw_pid, uint8_t arm_state) {
    motor_outputs_t outputs;

    // Safety Gate: Cut all power if disarmed or throttle is at zero stick
    if (arm_state == 0 || throttle_rc <= 0.05f) {
        outputs.front_left  = MOTOR_OFF;
        outputs.front_right = MOTOR_OFF;
        outputs.rear_left   = MOTOR_OFF;
        outputs.rear_right  = MOTOR_OFF;
        return outputs;
    }

    // Full Throttle
    // Map 0.0 - 1.0 directly to the full usable duty cycle range
    float base_throttle = MIN_ARMED_DUTY + (throttle_rc * (MAX_DUTY_CYCLE - MIN_ARMED_DUTY)); 

    // Mixing Matrix
    float m1 = base_throttle - pitch_pid + roll_pid + yaw_pid; // Front Left
    float m2 = base_throttle - pitch_pid - roll_pid - yaw_pid; // Front Right
    float m3 = base_throttle + pitch_pid + roll_pid - yaw_pid; // Rear Left
    float m4 = base_throttle + pitch_pid - roll_pid + yaw_pid; // Rear Right

    //  Mixer Scaling (Overflow / High-Throttle Desaturation)
    /*
    If a motor overflows past 100%, we calculate the exact overflow amount and subtract it from all four motors equally. This sacrifices a tiny amount of overall altitude, but preserves the differential thrust required to keep the drone from flipping.
    */
    // Find the highest commanded motor value
    float max_motor = m1;
    if (m2 > max_motor) max_motor = m2;
    if (m3 > max_motor) max_motor = m3;
    if (m4 > max_motor) max_motor = m4;

    // If any motor exceeds 100%, pull ALL motors down by the exact overflow amount.
    if (max_motor > MAX_DUTY_CYCLE) {
        float overflow = max_motor - MAX_DUTY_CYCLE;
        m1 -= overflow;
        m2 -= overflow;
        m3 -= overflow;
        m4 -= overflow;
    }

    // AirMode Scaling (Underflow / Zero-Throttle Desaturation)
    /*
    If pilot drops throttle to zero during a dive, the PID controller normally loses authority because the motors can't spin slower than the minimum idle speed. Underflow scaling detects this and slightly revs all motors up just enough to give the PID room to steer, keeping the drone perfectly stabilized even in a free-fall.
    */
    // Find the lowest commanded motor value after the overflow shift
    float min_motor = m1;
    if (m2 < min_motor) min_motor = m2;
    if (m3 < min_motor) min_motor = m3;
    if (m4 < min_motor) min_motor = m4;

    // If any motor drops below the minimum idle speed, push ALL motors up.
    if (min_motor < MIN_ARMED_DUTY) {
        float underflow = MIN_ARMED_DUTY - min_motor;
        m1 += underflow;
        m2 += underflow;
        m3 += underflow;
        m4 += underflow;
    }

    // Hardware Safety Clamp and Assignment
    // Fail-safe to guarantee no illegal values reach PWM hardware
    outputs.front_left  = (uint32_t)(m1 > MAX_DUTY_CYCLE ? MAX_DUTY_CYCLE : (m1 < MIN_ARMED_DUTY ? MIN_ARMED_DUTY : m1));
    outputs.front_right = (uint32_t)(m2 > MAX_DUTY_CYCLE ? MAX_DUTY_CYCLE : (m2 < MIN_ARMED_DUTY ? MIN_ARMED_DUTY : m2));
    outputs.rear_left   = (uint32_t)(m3 > MAX_DUTY_CYCLE ? MAX_DUTY_CYCLE : (m3 < MIN_ARMED_DUTY ? MIN_ARMED_DUTY : m3));
    outputs.rear_right  = (uint32_t)(m4 > MAX_DUTY_CYCLE ? MAX_DUTY_CYCLE : (m4 < MIN_ARMED_DUTY ? MIN_ARMED_DUTY : m4));

    return outputs;
}

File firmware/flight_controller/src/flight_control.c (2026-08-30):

#include <zephyr/kernel.h>
#include <zephyr/device.h>
#include <zephyr/drivers/sensor.h>
#include <zephyr/sys/printk.h>
#include <string.h>

#include "flight_control.h"
#include "radio_esb.h"
#include "modules/pid.h"
#include "modules/sensor_fusion.h"
#include "modules/motor_mixer.h"
#include "drivers/motor_pwm.h"
#include "modules/dynamic_notch.h"

#define RADIO_TIMEOUT_MS 500 

// Access the semaphore from the IMU driver
extern struct k_sem imu_data_ready_sem;

// This variable exists in radio_esb.c; declared and initialized there already, so use extern
extern int64_t last_packet_time; 

euler_angles_t current_angle = {0.0f, 0.0f, 0.0f};

// Making them static so they hold state across loops
static pid_controller pitch_pid;
static pid_controller roll_pid;
static pid_controller yaw_pid;

static dynamic_notch_t pitch_notch;
static dynamic_notch_t roll_notch;

void flight_controller_thread(void* p1, void* p2, void* p3){
    int64_t local_last_packet_time = 0;
    const struct device *bmi270 = DEVICE_DT_GET(DT_NODELABEL(bmi270));
    struct sensor_value accel[3];
    struct sensor_value gyro[3];
    data_packet local_rc_command;

    // Initialize PIDs.
    // Update to PID functions - Added 1.0f for the new Kb (anti-windup) parameter

    // Arguments in this order: p, i, d, b, i_limit, out_limit, cutoff_hz, sample_hz
    pid_init(&pitch_pid, 1.5f, 0.01f, 0.5f, 1.0f, 100.0f, 10000.0f, 30.0f, 1000.0f);
    pid_init(&roll_pid,  1.5f, 0.01f, 0.5f, 1.0f, 100.0f, 10000.0f, 30.0f, 1000.0f);
    pid_init(&yaw_pid,   1.5f, 0.01f, 0.5f, 1.0f, 100.0f, 10000.0f, 30.0f, 1000.0f); 

    // Initialize Dynamic Notch Filters for Gyro Channels to strip out motor vibration frequency
    dynamic_notch_init(&pitch_notch);
    dynamic_notch_init(&roll_notch);

    while(1){
        // Runs when IMU triggers data ready interrupt and gives semaphore to this fc thread
        k_sem_take(&imu_data_ready_sem, K_FOREVER);

        // get values from IMU
        sensor_sample_fetch(bmi270);
        sensor_channel_get(bmi270, SENSOR_CHAN_ACCEL_XYZ, accel);
        sensor_channel_get(bmi270, SENSOR_CHAN_GYRO_XYZ, gyro);

        // Convert Accel and Gyro to hardware floats because we do floating point math later 

        /*
            The nRF52840 uses an ARM Cortex-M4F processor ('F' stands for a hardware Floating-Point Unit (FPU)), making floating-point math extremely fast. Multiplying two floats takes 1 to 3 clock cycles, so practically as fast as integer math.

            It is single precision FPU, so need 32 bit float; Can't support 64 bit double.
            
        */
        float ax = sensor_value_to_double(&accel[0]);
        float ay = sensor_value_to_double(&accel[1]);
        float az = sensor_value_to_double(&accel[2]);
        
        float raw_gx = sensor_value_to_double(&gyro[0]);
        float raw_gy = sensor_value_to_double(&gyro[1]);
        float raw_gz = sensor_value_to_double(&gyro[2]);

        // Apply Dynamic Notch Filter to strip motor resonance
        float clean_gx = dynamic_notch_process(&roll_notch, raw_gx);
        float clean_gy = dynamic_notch_process(&pitch_notch, raw_gy);

        // Compute current orientation of drone
        sensor_fusion_compute(ax, ay, az, clean_gx, clean_gy, raw_gz, &current_angle, 0.001f);

        // Access shared memory
        // Get latest joystick positions from the radio thread
        k_spinlock_key_t key = k_spin_lock(&rc_spinlock);
        memcpy(&local_rc_command, &latest_rc_command, sizeof(data_packet));
        local_last_packet_time = last_packet_time; // Pull the timestamp
        k_spin_unlock(&rc_spinlock, key);

        // Failsafe - Did radio timeout, somehow rc disconnected, out of range etc?
        if ((k_uptime_get() - local_last_packet_time) > RADIO_TIMEOUT_MS) {
            motor_outputs_t kill_output = {0, 0, 0, 0};
            app_pwm_set(&kill_output);
            continue; // Skip PID math 
        }

        // Update PID loops 
        float pitch_correction = pid_update(&pitch_pid, local_rc_command.pitch, current_angle.pitch, 0.001f);
        float roll_correction  = pid_update(&roll_pid,  local_rc_command.roll,  current_angle.roll,  0.001f);
        float yaw_correction   = pid_update(&yaw_pid,   local_rc_command.yaw,   current_angle.yaw,   0.001f);

        // Mix outputs and send to motors
        motor_outputs_t output = mix_motors(local_rc_command.throttle, pitch_correction, roll_correction, yaw_correction, local_rc_command.status);
        app_pwm_set(&output);   
    }
}

K_THREAD_DEFINE(fc_thread_id, 2048, flight_controller_thread, NULL, NULL, NULL, -1, 0, 0);

/*
A preemptive thread can be interrupted by the OS scheduler if a higher-priority task wakes up. If FC thread is halfway through calculating the PID loop and kernel pauses it to run the ESB thread, motor updates will be delayed. This causes jitter and messes up the DSP pipeline.
*/

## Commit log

2026-06-20 Added IMU sensor logic + PCB files
    [Flight_Controller.PcbDoc, Flight_Controller.SchDoc, Mini-Drone-FC.PrjPcb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]
2026-06-20 Enhance README with flight controller and remote board details
    Added detailed sections for flight controller and remote control boards, including images and assembly progress.
2026-06-21 Finalize project structure, create files; Added Sensor Fusion, IMU, and flight control thread high-level
2026-06-22 Update drone-journal, overlay and sensor fusion code
2026-06-28 Update FC with PID and motor mixers; Set PWM
2026-06-28 Add Flight Controller Board details to README
    Updated the README to include detailed information about the Flight Controller Board, its architecture, and testing procedures.
2026-06-28 Added Schematic PDFs
2026-06-28 Revise hardware design details in README
    Updated hardware design section with detailed descriptions of the flight controller and remote controller, including schematics and layout views.
2026-07-20 Update README with new images for assembly and testing
    Added additional images to the Mechanical Structure and Testing IMU sections.
2026-07-26 Add CMSIS-DSP integration details to README
    Updated README to include details on CMSIS-DSP integration in the flight controller firmware, addressing D-term motor heating, dynamic notch filtering for motor resonance, and improvements in sensor 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
2026-08-29 DSP PID fix for derivative kick and anti-windup
    [flight_control.c]
2026-08-30 Update DSP Pipeline + motor thrust clamps
